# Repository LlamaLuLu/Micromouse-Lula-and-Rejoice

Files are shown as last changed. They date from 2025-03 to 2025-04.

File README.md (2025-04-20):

# 🐭 Micromouse Power Subsystem – EEE3088F 2025

> A modular and cost-efficient power subsystem designed for the Micromouse platform, focusing on power delivery, battery management, voltage regulation, and motor control.  
> 🔧 Built to integrate with a shared motherboard using a 2×16 pin header.

---

## 📐 Design Requirements

- Must interface with **shared motherboard via 2×16 pin header**
- All subsystems must **interoperate safely and reliably**
- Total cost must not exceed **$28.25 per student**
- Designed with **PCB production in mind** (JLCPCB compatible)

---

## ⚡ Subsystems Overview

### 1. USB-C Power Input
- **Objective**: Extract and regulate power from USB-C
- **Default Output**: 5V  
- **Target Output**: 9V
- **Approaches**:
  - Step-up converter (boost from 5V)
  - Request 9V from port using USB PD (Power Delivery) negotiation

### 2. Battery Management
- **Battery**: 3.7V 800mAh LiPo (used in micro robotics)
- **Charging Input**: 9V (from USB-C)
- **Charging Modes**:
  - Low current: **200mA**
  - High current: **(600 ± 100)mA**
- **Key Considerations**:
  - LiPo is **sensitive to overcharging**
- **Design Strategies**:
  - Use a **battery management IC**
  - Dual-mode charging circuit (selectable)
    - Separate high- and low-current paths
  - OR: Current regulation on USB-C input side that supports both modes

### 3. Power Switching & Regulation

#### 🔌 Power Switch
- Enables/disables battery output to downstream circuits

#### 🔋 Voltage Regulation
- Battery output can supply up to **400mA**
- **Approach**: Efficient voltage regulation using buck converters
- **Protection**: Optional current amplification for regulated rails

#### 🔀 External Load Switching
- Must control **2 external loads**, each up to **1A**
- **Solution**: High-current **MOSFET switching circuits**
- Current path design considers **external load values**

### 4. Components & Motor Drivers

#### 🔍 Current Sensor
- **INA219** or similar  
- Connects via **I²C**  
- Placed on high-side battery line for real-time monitoring

#### 🚗 Motor Control
- **Primary Motors**: 2 × 200mA  
- **Auxiliary Motors**: 2 × 500mA  
- Control via **dual H-bridge** motor driver (e.g., DRV8833)
- Motors driven bidirectionally using **PWM from MCU**

---

## 🧰 Production & Submission Instructions (EEE3088F)

The final PCB submission is in a zipped folder:
[Final PCB Files](./EEE3088F_PCB_Project/jlcpcb/production_files/EEE3088F_2025_Project_PCB_Files_Group_66_LNGLUL002_MTMREJ003.zip)

_ZIP File Includes:_
1. Zipped **Gerber** files (with silkscreen including group & student numbers)
2. **BOM `.csv`** file  
3. **POS/CPL `.csv`** file  
4. Screenshot of **JLCPCB BOM upload** page  
5. Screenshot of **JLCPCB Add to Cart** confirmation page  

📷 PCB Design:
- Schematic
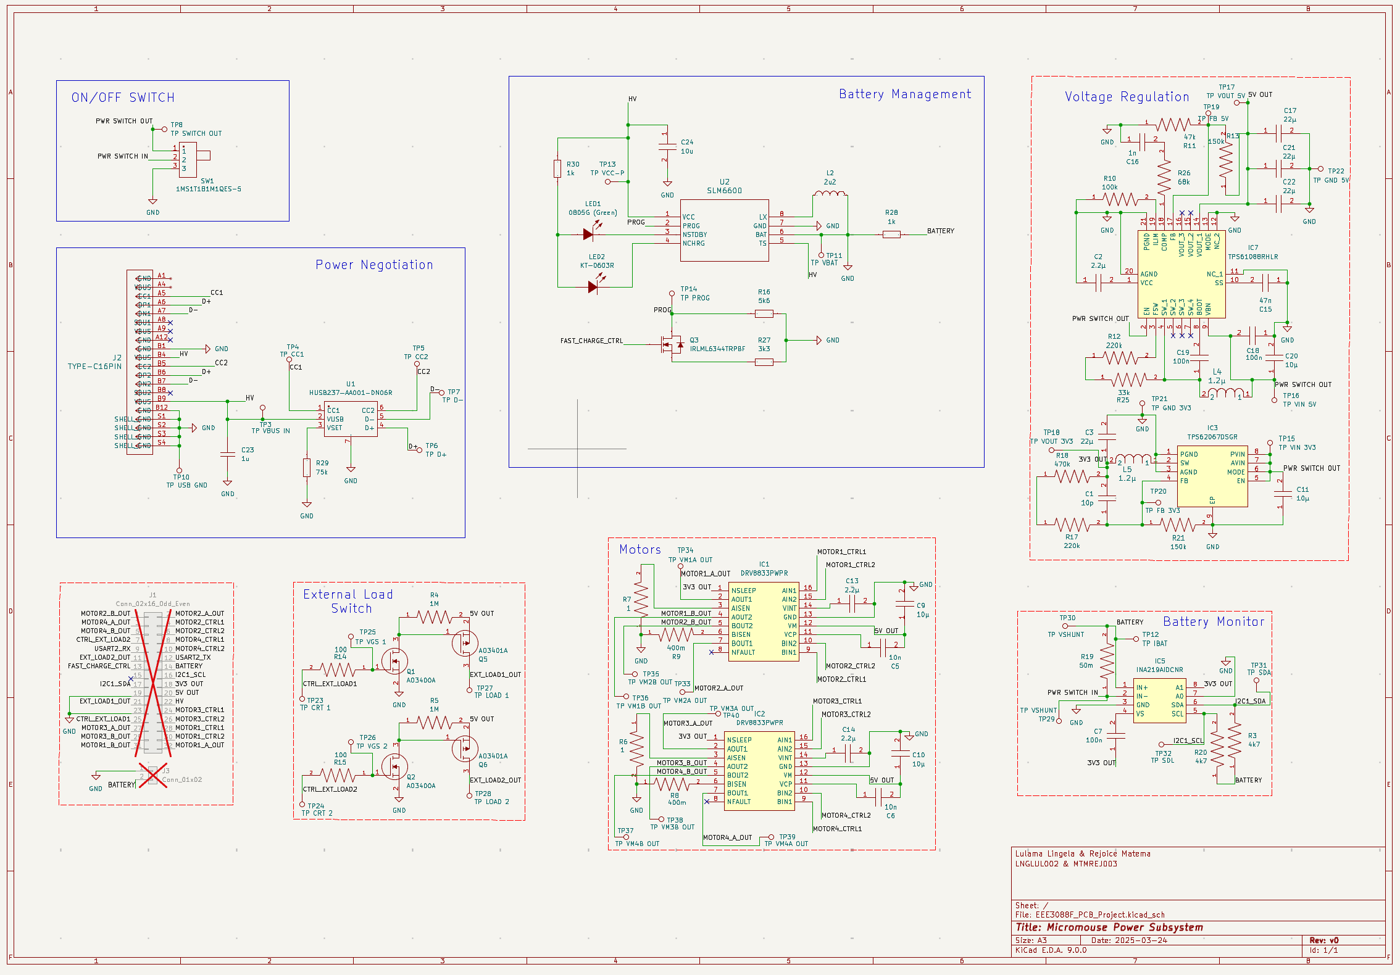
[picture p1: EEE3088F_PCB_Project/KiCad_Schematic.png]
KiCad Schematic

- PCB Wiring
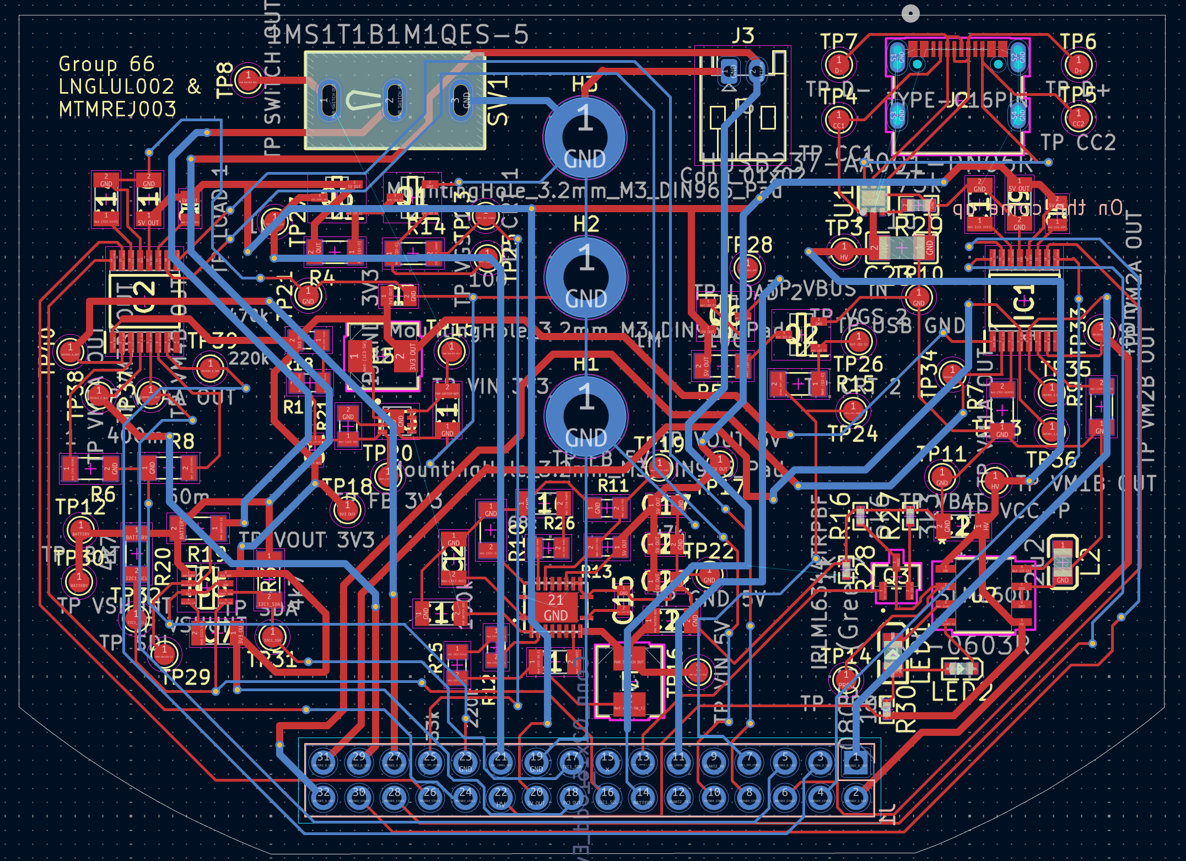
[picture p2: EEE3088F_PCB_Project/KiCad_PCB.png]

- JLCPCB Design (Front)
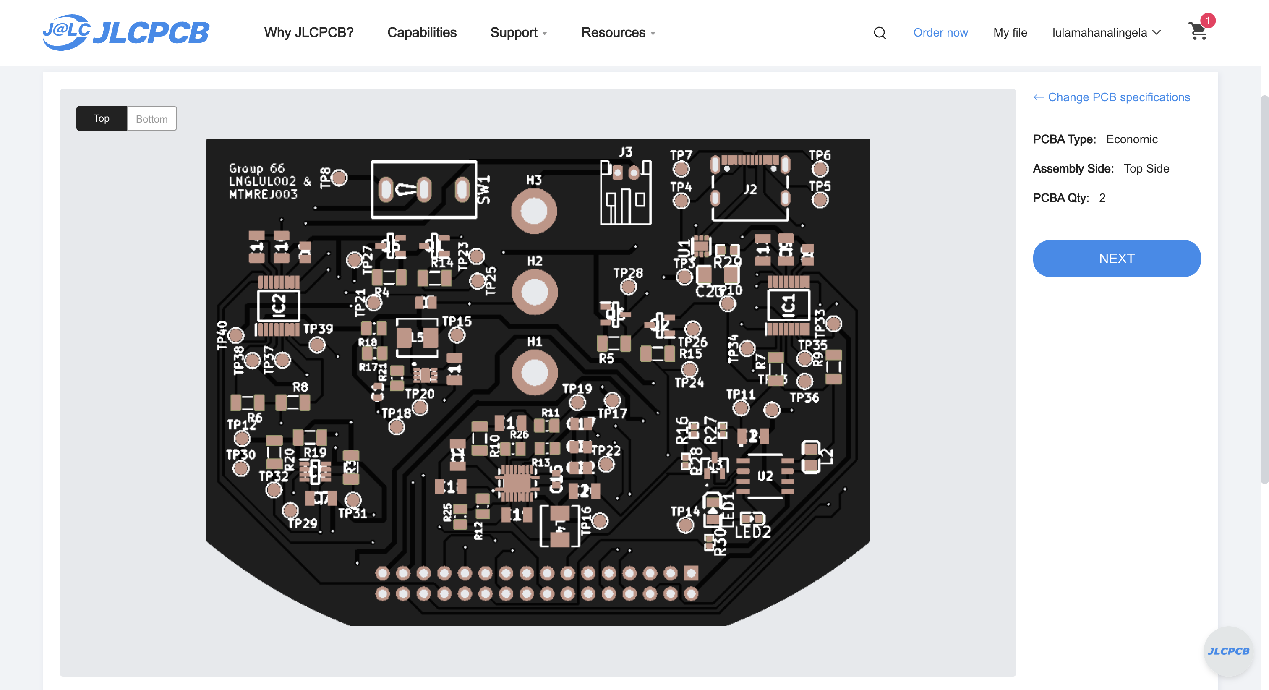
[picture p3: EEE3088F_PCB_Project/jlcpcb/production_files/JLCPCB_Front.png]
JLCPCB Acceptance Screenshot

- JLCPCB Design (Back)
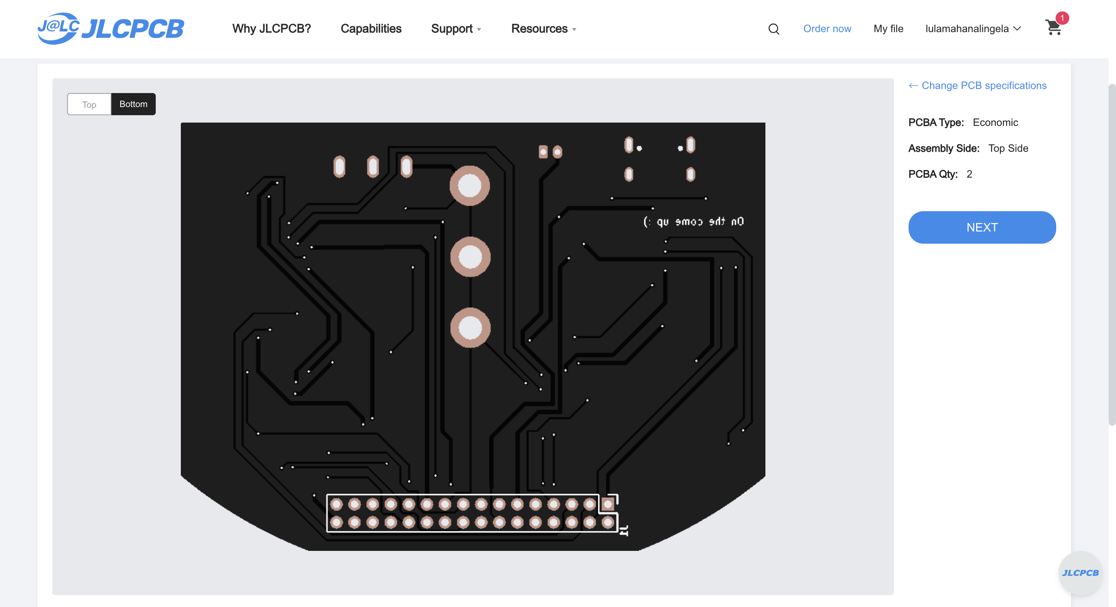
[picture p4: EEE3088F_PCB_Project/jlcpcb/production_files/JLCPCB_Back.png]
JLCPCB Acceptance Screenshot


---

## 👨‍💻 Authors: Group 66

- **Lulama Lingela** (LNGLUL002)
- **Rejoice Matema** (MTMREJ003)

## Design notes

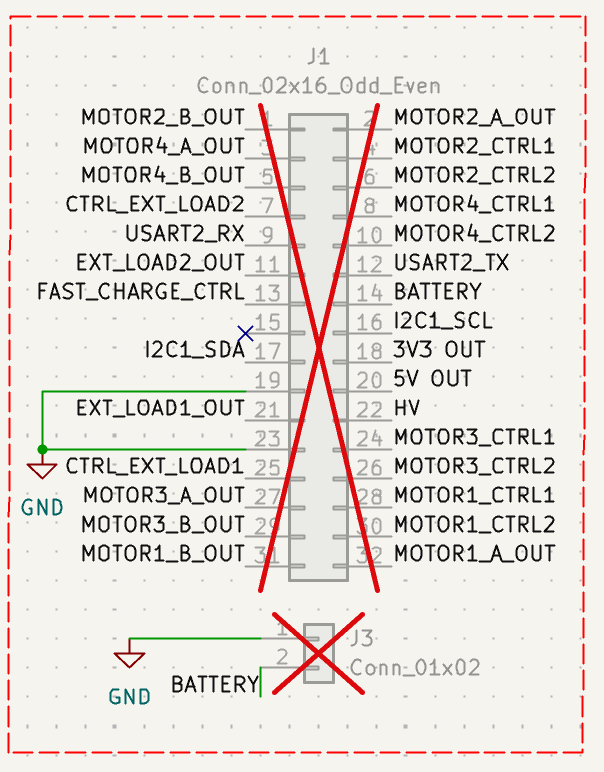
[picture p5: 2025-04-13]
EEE3088F_PCB_Project/schematics v1/Screenshot 2025-03-28 at 20.44.02.png

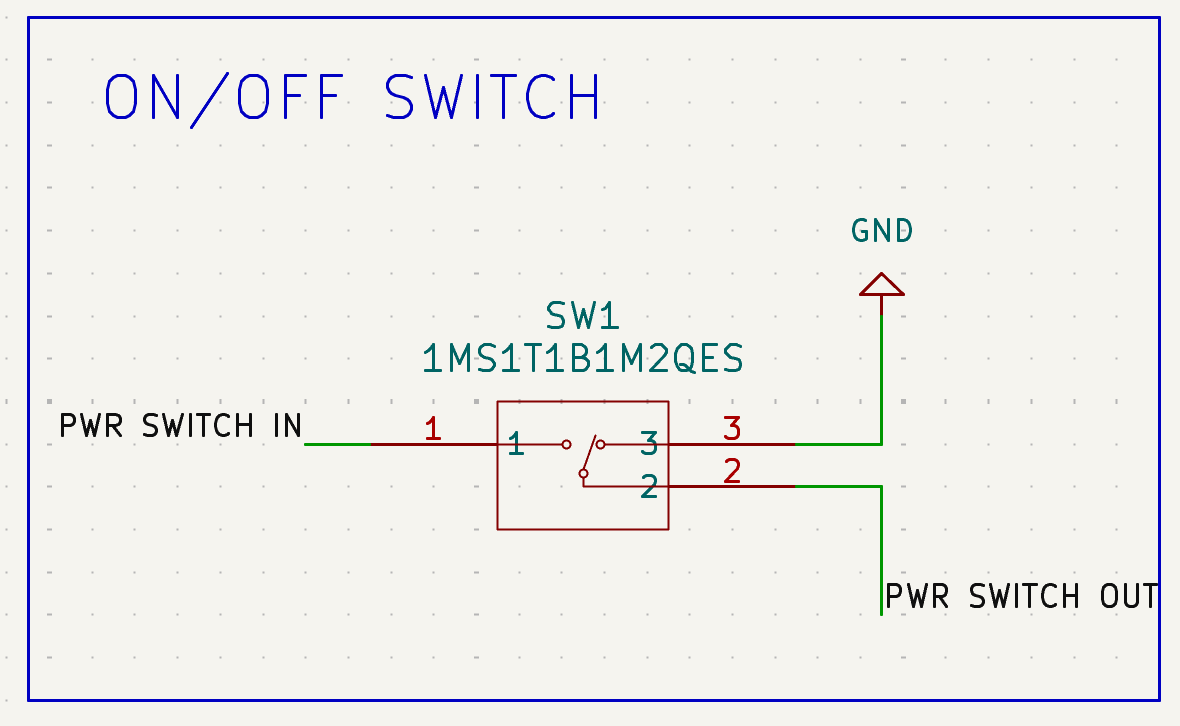
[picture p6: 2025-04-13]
EEE3088F_PCB_Project/schematics v1/Screenshot 2025-03-28 at 20.43.12.png

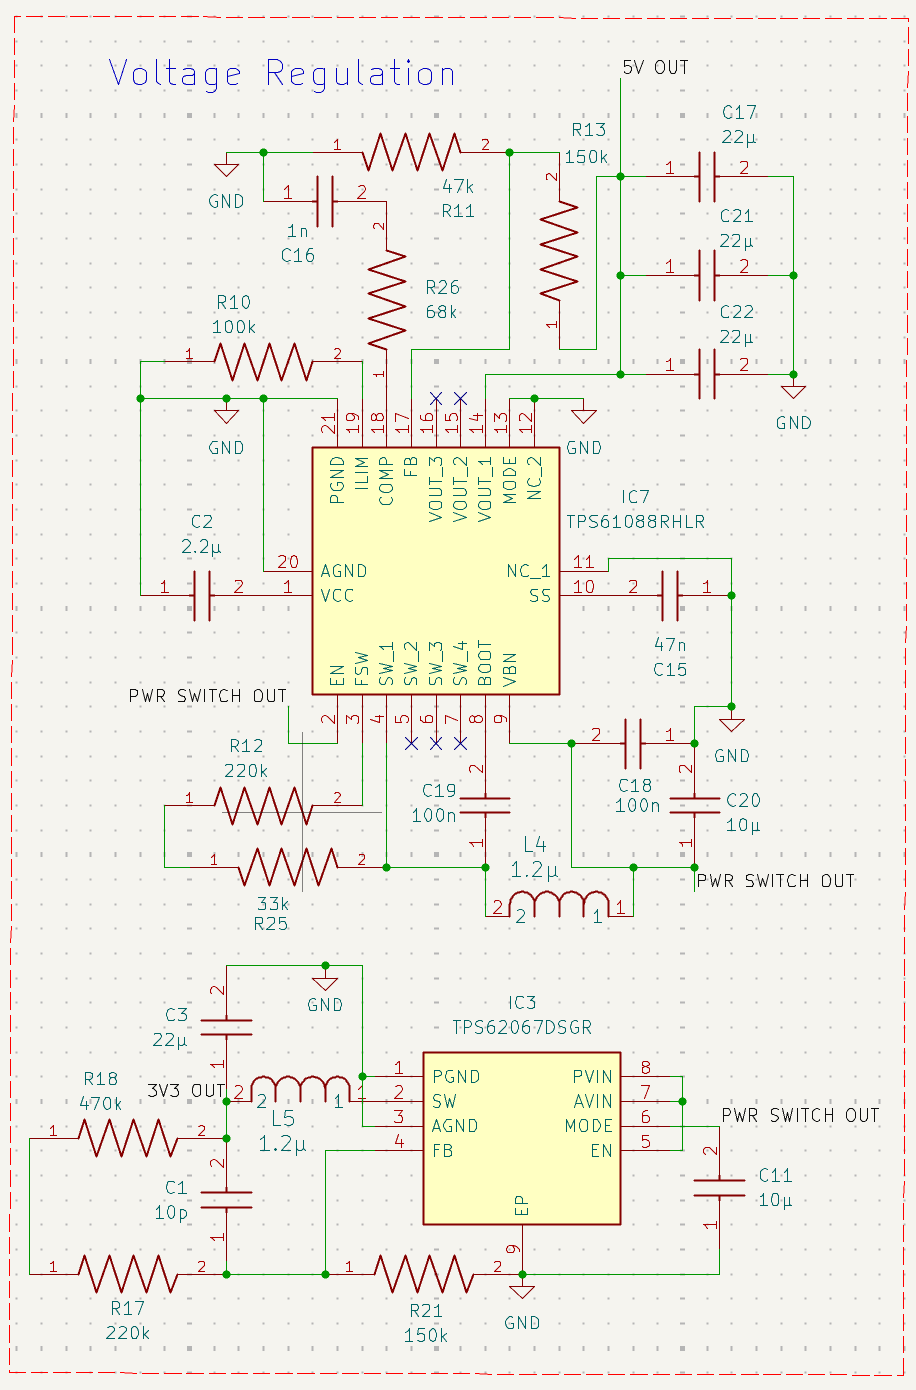
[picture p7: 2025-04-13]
EEE3088F_PCB_Project/schematics v1/Screenshot 2025-03-28 at 20.43.32.png

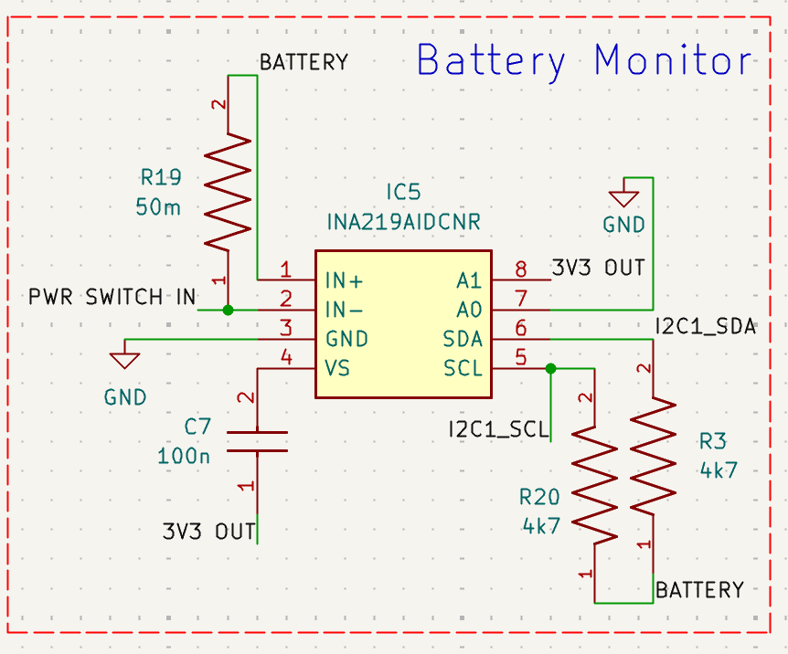
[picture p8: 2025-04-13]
EEE3088F_PCB_Project/schematics v1/Screenshot 2025-03-28 at 20.43.53.png

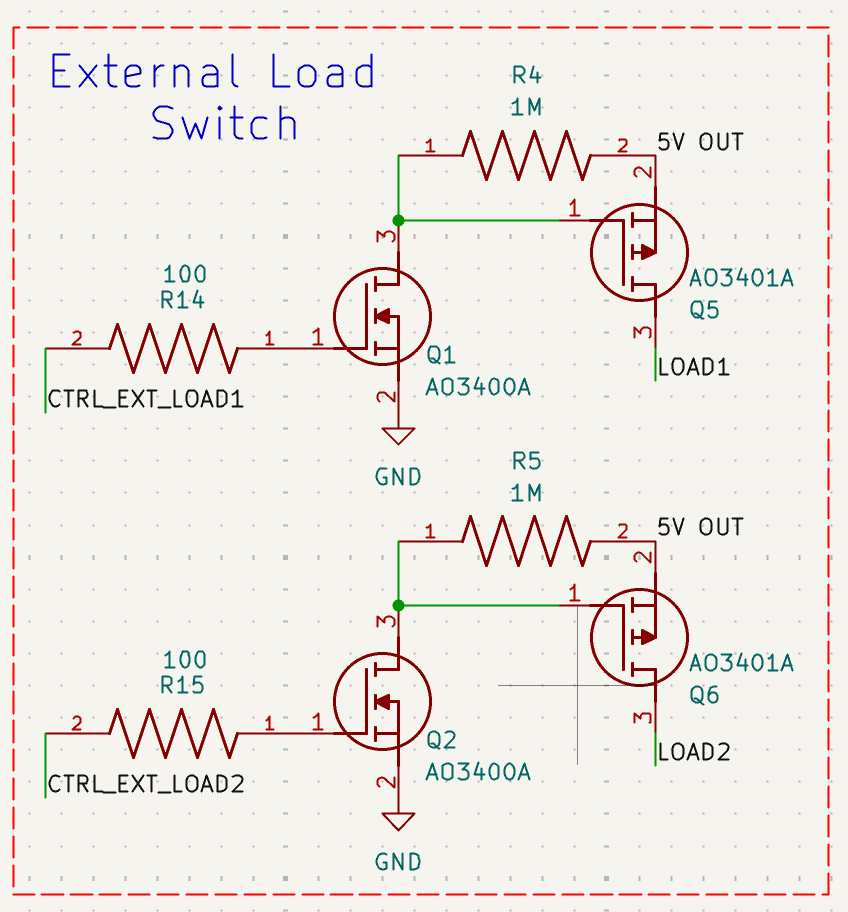
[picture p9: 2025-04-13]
EEE3088F_PCB_Project/schematics v1/Screenshot 2025-03-28 at 20.43.48.png

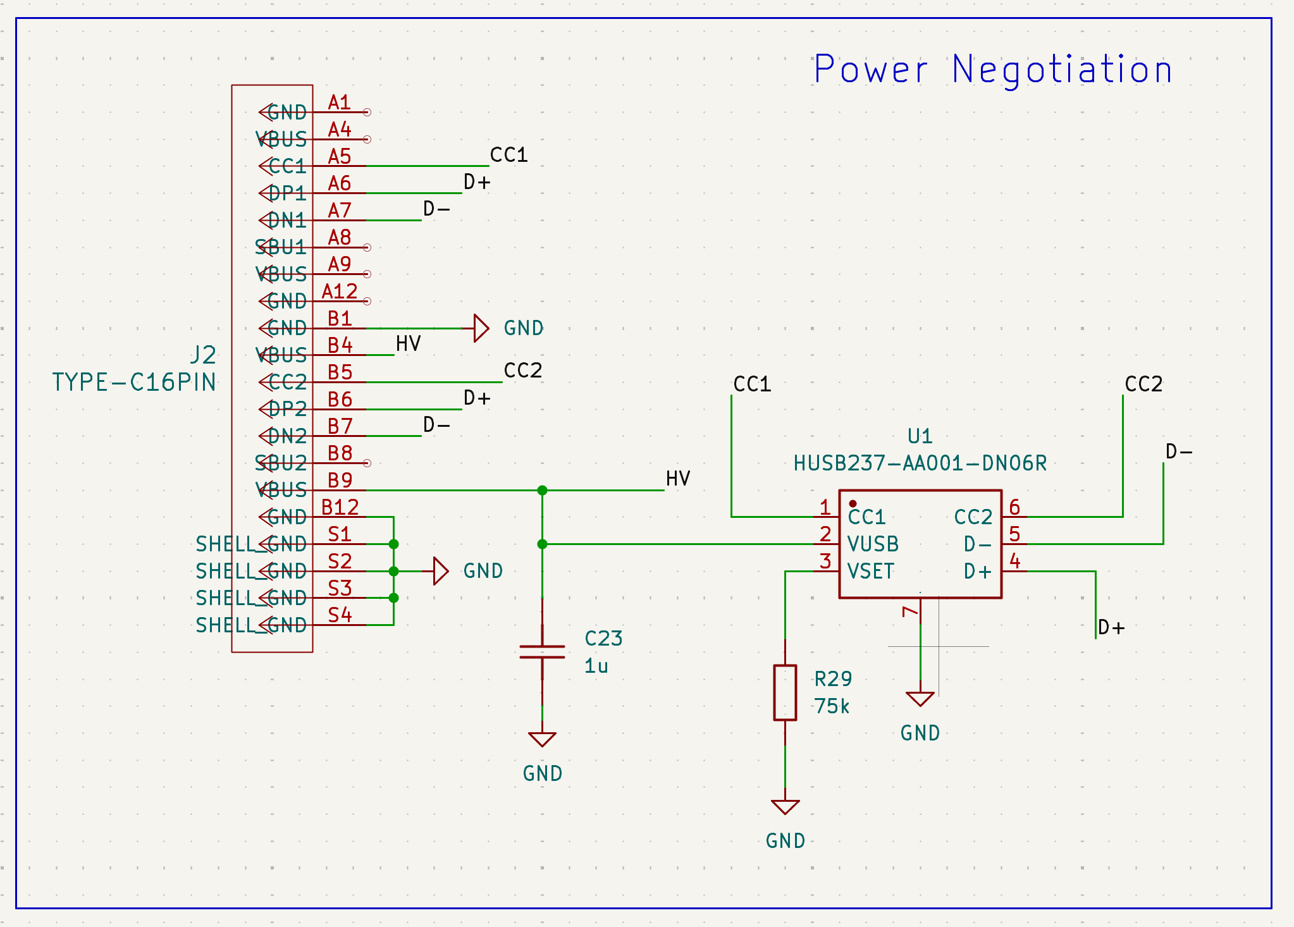
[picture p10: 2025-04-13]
EEE3088F_PCB_Project/schematics v1/Screenshot 2025-03-28 at 20.43.07.png

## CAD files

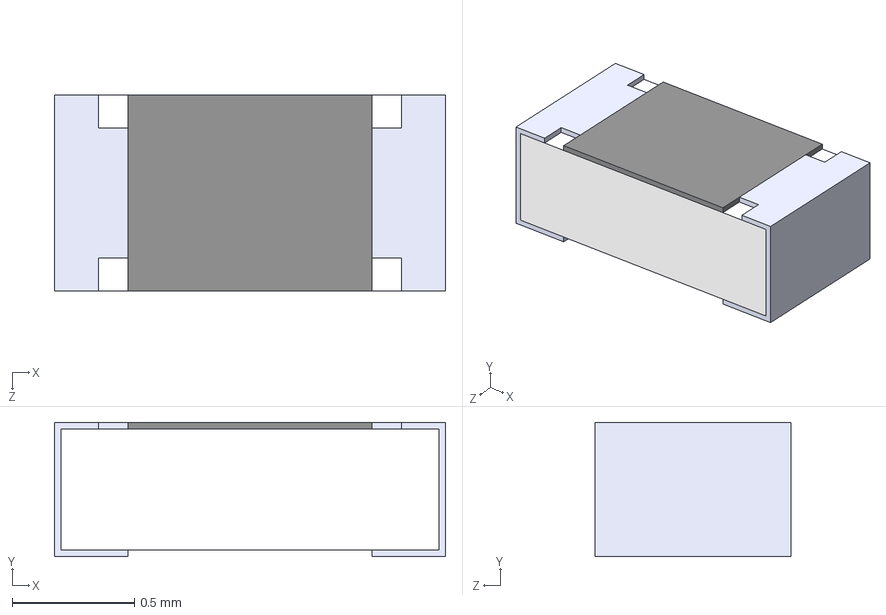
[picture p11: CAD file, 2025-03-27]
EEE3088F_PCB_Project/Imported components/0603WAF1203T5E/0603WAF1203T5E.step
1.60 x 0.55 x 0.8 mm

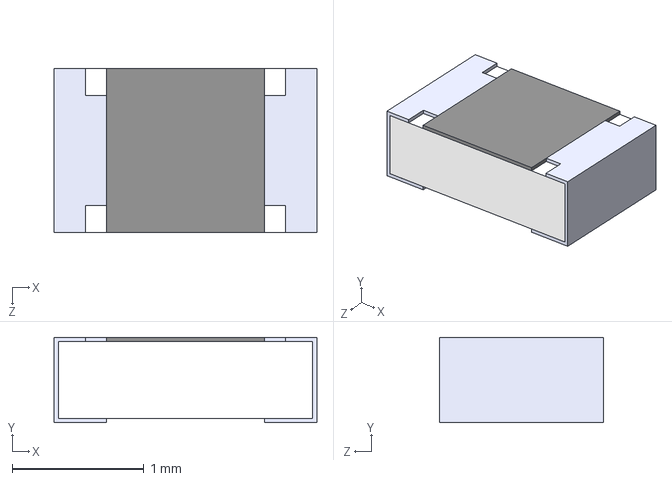
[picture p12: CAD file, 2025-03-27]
EEE3088F_PCB_Project/Imported components/0805W8F4702T5E/0805W8F4702T5E.step
2.00 x 0.65 x 1.25 mm

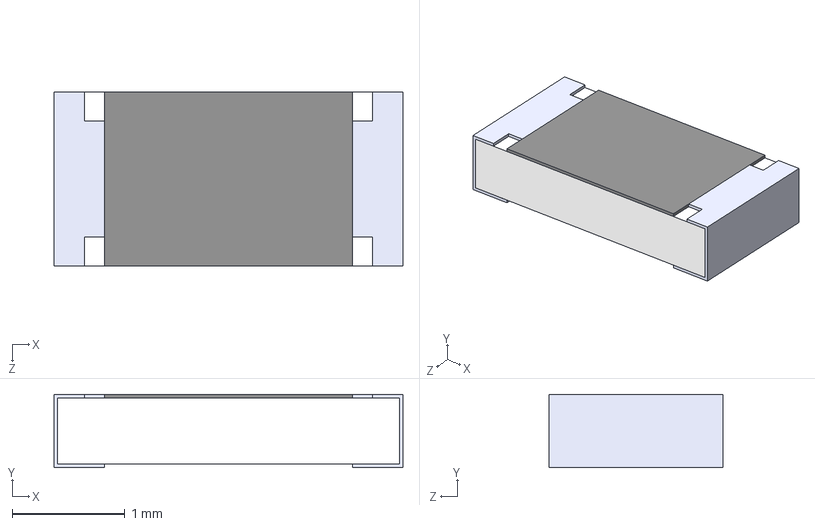
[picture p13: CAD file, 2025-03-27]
EEE3088F_PCB_Project/Imported components/1206W3F500MT5E/1206W3F500MT5E.step
3.10 x 0.65 x 1.55 mm

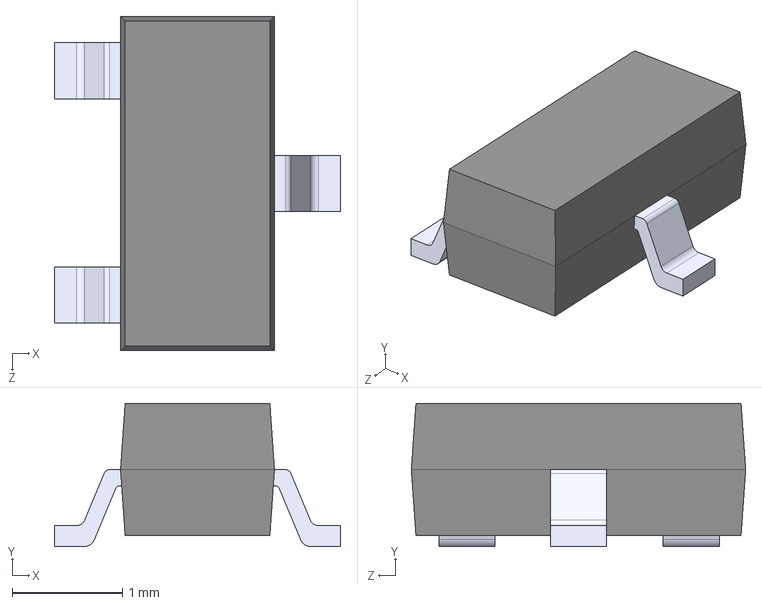
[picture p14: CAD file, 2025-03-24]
EEE3088F_PCB_Project/Imported components/MMBT2222A/MMBT2222A.step
2.60 x 1.30 x 3.04 mm

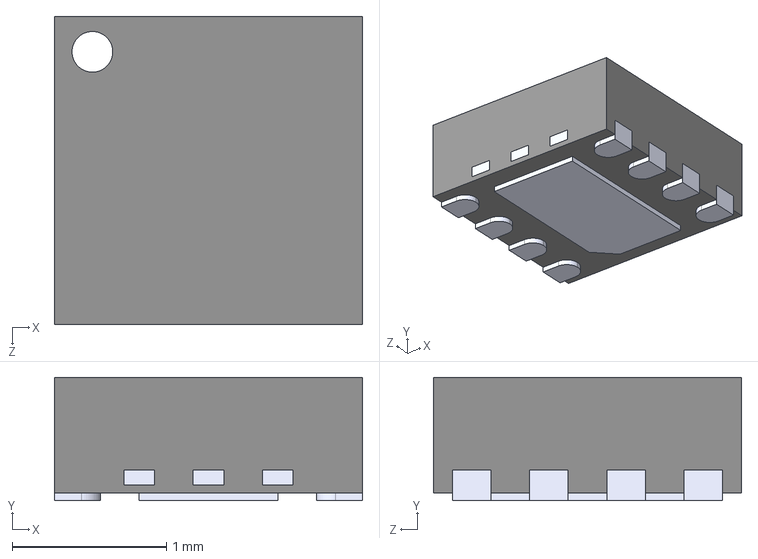
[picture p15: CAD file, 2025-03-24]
EEE3088F_PCB_Project/Imported components/TPS62067DSGR/TPS62067DSGR.step
2.00 x 0.8 x 2.00 mm

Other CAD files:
EEE3088F_PCB_Project/Imported components/1206W4F1004T5E/1206W4F1004T5E.step

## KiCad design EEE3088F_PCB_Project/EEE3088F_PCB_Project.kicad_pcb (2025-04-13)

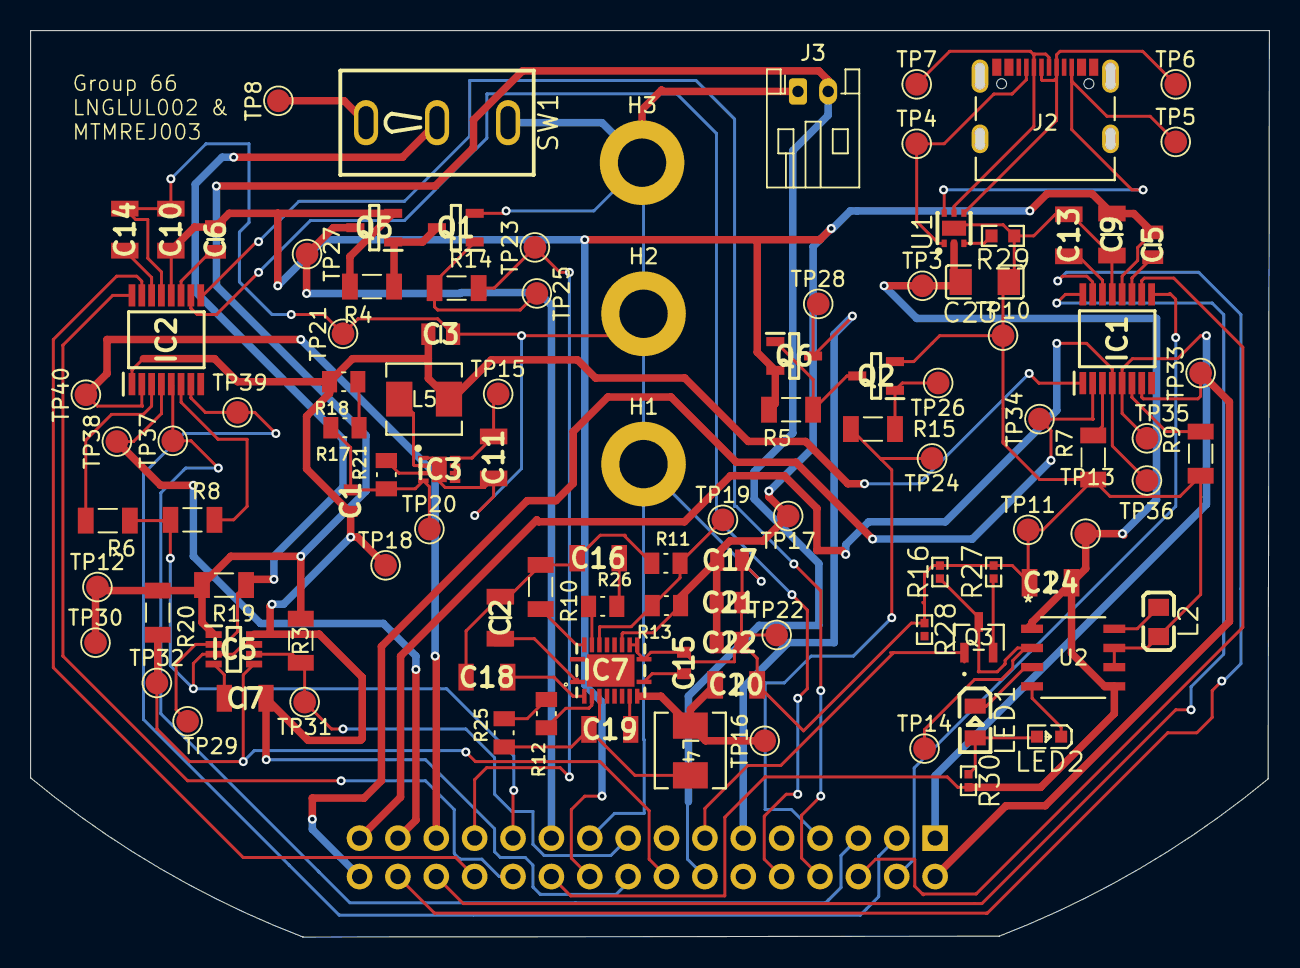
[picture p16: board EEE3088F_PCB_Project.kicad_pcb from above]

Board: 2 copper layers, 82.0 x 60.0 mm, 107 parts (1 on the bottom side), 67 nets.

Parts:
C1: 10p; CAPC1608X90N
C2, C13, C14: 2.2µ; CAPC3216X180N
C3, C17, C21, C22: 22µ; CAPC2012X140N
C5, C6: 10n; CAPC2012X75N
C7, C18, C19: 100n; CAPC3216X100N
C9, C10, C11, C20: 10µ; CAPC3216X180N
C15: 47n; CAPC1608X90N
C16: 1n; CAPC3215X163N
C23: 1u; C1206
C24: 10u; CAPC3216X180N
H1, H2, H3: MountingHole_3.2mm_M3_DIN965_Pad
IC1, IC2: DRV8833PWPR; SOP65P640X120-16N
IC3: TPS62067DSGR; SON50P200X200X80-9N
IC5: INA219AIDCNR; SOP65P280X145-8N
IC7: TPS61088RHLR; RHL_R-PVQFN-N20__1
J1: Conn_02x16_Odd_Even; PinSocket_2x16_P2.54mm_Vertical
J2: TYPE-C16PIN; CONN16_C16PIN_SHN
J3: Conn_01x02; JST_PH_S2B-PH-K_1x02_P2.00mm_Horizontal
L2: 2u2; L0805
L4, L5: 1.2µ; IND_FXL0420_CMT
LED1: 0805G (Green); LED0805-R-RD
LED2: KT-0603R; LED0603-RD
Q1, Q2: AO3400A; SOT95P280X125-3N
Q3: IRLML6344TRPBF; IRLML6344TRPBF_INF
Q5, Q6: AO3401A; SOT95P280X125-3N
R3, R20: 4k7; RESC3115X65N
R4, R5: 1M; RESC3115X65N
R6, R7: 1; RESC3115X65N
R8, R9: 400m; RESC3115X65N
R10: 100k; RESC3115X65N
R11: 47k; RESC2012X65N
R12, R17: 220k; RESC2012X65N
R13, R21: 150k; RESC2012X65N
R14, R15: 100; RESC3115X65N
R16: 5k6; R0402
R18: 470k; RESC2012X65N
R19: 50m; RESC3115X65N
R25: 33k; RESC2012X65N
R26: 68k; RESC2012X65N
R27: 3k3; R0402
R28, R30: 1k; R0402
R29: 75k; R0603
SW1: 1MS1T1B1M1QES-5; SW-TH_1MS1T1B1M1QES-5
TP3: TP VBUS IN; TestPoint_Pad_D1.5mm
TP4: TP CC1; TestPoint_Pad_D1.5mm
TP5: TP CC2; TestPoint_Pad_D1.5mm
TP6: TP D+; TestPoint_Pad_D1.5mm
TP7: TP D-; TestPoint_Pad_D1.5mm
TP8: TP SWITCH OUT; TestPoint_Pad_D1.5mm
TP10: TP USB GND; TestPoint_Pad_D1.5mm
TP11: TP VBAT; TestPoint_Pad_D1.5mm
TP12: TP IBAT; TestPoint_Pad_D1.5mm
TP13: TP VCC-P; TestPoint_Pad_D1.5mm
TP14: TP PROG; TestPoint_Pad_D1.5mm
TP15: TP VIN 3V3; TestPoint_Pad_D1.5mm
TP16: TP VIN 5V; TestPoint_Pad_D1.5mm
TP17: TP VOUT 5V; TestPoint_Pad_D1.5mm
TP18: TP VOUT 3V3; TestPoint_Pad_D1.5mm
TP19: TP FB 5V; TestPoint_Pad_D1.5mm
TP20: TP FB 3V3; TestPoint_Pad_D1.5mm
TP21: TP GND 3V3; TestPoint_Pad_D1.5mm
TP22: TP GND 5V; TestPoint_Pad_D1.5mm
TP23: TP CRT 1; TestPoint_Pad_D1.5mm
TP24: TP CRT 2; TestPoint_Pad_D1.5mm
TP25: TP VGS 1; TestPoint_Pad_D1.5mm
TP26: TP VGS 2; TestPoint_Pad_D1.5mm
TP27: TP LOAD 1; TestPoint_Pad_D1.5mm
TP28: TP LOAD 2; TestPoint_Pad_D1.5mm
TP29, TP30: TP VSHUNT; TestPoint_Pad_D1.5mm
TP31: TP SDA; TestPoint_Pad_D1.5mm
TP32: TP SDL; TestPoint_Pad_D1.5mm
TP33: TP VM2A OUT; TestPoint_Pad_D1.5mm
TP34: TP VM1A OUT; TestPoint_Pad_D1.5mm
TP35: TP VM2B OUT; TestPoint_Pad_D1.5mm
TP36: TP VM1B OUT; TestPoint_Pad_D1.5mm
TP37: TP VM4B OUT; TestPoint_Pad_D1.5mm
TP38: TP VM3B OUT; TestPoint_Pad_D1.5mm
TP39: TP VM4A OUT; TestPoint_Pad_D1.5mm
TP40: TP VM3A OUT; TestPoint_Pad_D1.5mm
U1: HUSB237-AA001-DN06R; TDFN-6_L2.0-W2.0-P0.65-TL-EP
U2: SLM6600; SOP8_4X5P1-1P27_SOI

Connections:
/3V3 OUT: C1.2, C3.1, C7.1, IC1.1 (NSLEEP), IC2.1 (NSLEEP), IC5.8 (A1), J1.18, L5.2, R18.2, TP18.1
/5V OUT: C5.2, C6.2, C9.1, C10.1, C17.1, C21.1, C22.1, IC1.12 (VM), IC2.12 (VM), IC7.14 (VOUT_1), J1.20, Q5.2 (S), Q6.2 (S), R4.2, R5.2, R13.1, TP17.1
/BATTERY: IC5.1 (IN+), J1.14, J3.2, R3.1, R19.2, R20.1, R28.2, TP12.1, TP30.1
/CC1: J2.A5 (CC1), TP4.1, U1.1 (CC1)
/CC2: J2.B5 (CC2), TP5.1, U1.6 (CC2)
/CTRL_EXT_LOAD1: J1.25, R14.2, TP23.1
/CTRL_EXT_LOAD2: J1.7, R15.2, TP24.1
/D+: J2.A6 (DP1), J2.B6 (DP2), TP6.1, U1.4 (D+)
/D-: J2.A7 (DN1), J2.B7 (DN2), TP7.1, U1.5 (D-)
/EXT_LOAD1_OUT: J1.21, Q5.3 (D), TP27.1
/EXT_LOAD2_OUT: J1.11, Q6.3 (D), TP28.1
/FAST_CHARGE_CTRL: J1.13, Q3.1 (G)
/HV: C23.2, C24.1, J1.22, J2.B4 (VBUS), J2.B9 (VBUS), R30.2, TP3.1, TP13.1, U1.2 (VUSB), U2.1 (VCC), U2.5 (TS)
/I2C1_SCL: IC5.5 (SCL), J1.16, R20.2, TP32.1
/I2C1_SDA: IC5.6 (SDA), J1.17, R3.2, TP31.1
/MOTOR1_A_OUT: IC1.2 (AOUT1), J1.32, TP34.1
/MOTOR1_B_OUT: IC1.4 (AOUT2), J1.31, TP36.1
/MOTOR1_CTRL1: IC1.16 (AIN1), J1.28
/MOTOR1_CTRL2: IC1.15 (AIN2), J1.30
/MOTOR2_A_OUT: IC1.7 (BOUT1), J1.2, TP33.1
/MOTOR2_B_OUT: IC1.5 (BOUT2), J1.1, TP35.1
/MOTOR2_CTRL1: IC1.9 (BIN1), J1.4
/MOTOR2_CTRL2: IC1.10 (BIN2), J1.6
/MOTOR3_A_OUT: IC2.2 (AOUT1), J1.27, TP40.1
/MOTOR3_B_OUT: IC2.4 (AOUT2), J1.29, TP38.1
/MOTOR3_CTRL1: IC2.16 (AIN1), J1.24
/MOTOR3_CTRL2: IC2.15 (AIN2), J1.26
/MOTOR4_A_OUT: IC2.7 (BOUT1), J1.3, TP39.1
/MOTOR4_B_OUT: IC2.5 (BOUT2), J1.5, TP37.1
/MOTOR4_CTRL1: IC2.9 (BIN1), J1.8
/MOTOR4_CTRL2: IC2.10 (BIN2), J1.10
/PROG: Q3.3 (D), R16.1, TP14.1, U2.2 (PROG)
/PWR SWITCH IN: IC5.2 (IN-), R19.1, SW1.2, TP29.1
/PWR SWITCH OUT: C11.2, C18.2, C20.1, IC3.5 (EN), IC3.6 (MODE), IC3.7 (AVIN), IC3.8 (PVIN), IC7.2 (EN), IC7.9 (VBN), L4.1, SW1.1, TP8.1, TP15.1, TP16.1
GND: C2.1, C3.2, C9.2, C10.2, C11.1, C13.2, C14.2, C15.1, C16.1, C17.2, C18.1, C20.2, C21.2, C22.2, C23.1, C24.2, H1.1, H2.1, H3.1, IC1.13 (GND), IC2.13 (GND), IC3.1 (PGND), IC3.3 (AGND), IC3.9 (EP), IC5.3 (GND), IC5.7 (A0), IC7.11 (NC_1), IC7.12 (NC_2), IC7.13 (MODE), IC7.20 (AGND), IC7.21 (PGND), J1.19, J1.23, J2.B1 (GND), J2.B12 (GND), J2.S1 (SHELL_GND), J2.S2 (SHELL_GND), J2.S3 (SHELL_GND), J2.S4 (SHELL_GND), J3.1, L2.2, Q1.2 (S), Q2.2 (S), R6.2, R7.1, R8.1, R9.1, R10.1, R11.1, R16.2, R21.2, R27.2, R28.1, R29.1, SW1.3, TP10.1, TP11.1, TP21.1, TP22.1, U1.7 (GND), U2.6 (BAT), U2.7 (GND)
unnamed: C16.2, R26.2
unnamed: IC1.3 (AISEN), R7.2
unnamed: IC1.6 (BISEN), R9.2
unnamed: C5.1, IC1.11 (VCP)
unnamed: C13.1, IC1.14 (VINT)
unnamed: IC2.3 (AISEN), R6.1
unnamed: IC2.6 (BISEN), R8.2
unnamed: C6.1, IC2.11 (VCP)
unnamed: C14.1, IC2.14 (VINT)
unnamed: C1.1, IC3.4 (FB), R17.2, R21.1, TP20.1
unnamed: IC3.2 (SW), L5.1
unnamed: C7.2, IC5.4 (VS)
unnamed: C19.2, IC7.8 (BOOT)
unnamed: IC7.18 (COMP), R26.1
unnamed: IC7.17 (FB), R11.2, R13.2, TP19.1
unnamed: IC7.3 (FSW), R12.2
unnamed: IC7.19 (ILIM), R10.2
unnamed: C15.2, IC7.10 (SS)
unnamed: C19.1, IC7.4 (SW_1), L4.2, R25.2
unnamed: C2.2, IC7.1 (VCC)
unnamed: LED1.1 (A), LED2.2 (A), R30.1
unnamed: LED1.2 (K), U2.3 (NSTDBY)
unnamed: LED2.1 (K), U2.4 (NCHRG)
unnamed: Q1.3 (D), Q5.1 (G), R4.1
unnamed: Q1.1 (G), R14.1, TP25.1
unnamed: Q2.3 (D), Q6.1 (G), R5.1
unnamed: Q2.1 (G), R15.1, TP26.1
unnamed: Q3.2 (S), R27.1
unnamed: R12.1, R25.1
unnamed: R17.1, R18.1
unnamed: R29.2, U1.3 (VSET)
unnamed: L2.1, U2.8 (LX)

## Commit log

2025-03-24 v0
    KiCad project set up
    [EEE3088F_PCB_Project.kicad_pcb, EEE3088F_PCB_Project.kicad_sch]
2025-03-24 v0.1
    Lula: Essential components for my requirements imported to KiCad
    [AO3401A.step, DRV8833PWPR.step, EEE3088F_PCB_Project.kicad_sch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]
2025-03-24 v0.1.1
    Lula: Rearranged position of components to make space for others
    [EEE3088F_PCB_Project.kicad_sch]
2025-03-24 v0.1.2
    Lula: Updated ICs with more compact symbols from Component Search Engine
    [DRV8833PWPR.step, EEE3088F_PCB_Project.kicad_sch, INA219AIDCNR.step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]
2025-03-24 v0.1.3
    Lula: Deleted old IC file
    [AO3401A.step]
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2025-03-25 v0.2
    Lula: rough battery monitor circuit done
    [EEE3088F_PCB_Project.kicad_sch]
2025-03-25 v0.2.1
    Lula: Making progress with Motor cct
    [EEE3088F_PCB_Project.kicad_sch]
2025-03-25 v0.3
    Lula: rough schematic for motors done
    [EEE3088F_PCB_Project.kicad_sch]
2025-03-25 v0.4
    Lula: rough voltage regulator circuits done but bias resistor values not calculated
    [EEE3088F_PCB_Project.kicad_sch, TPS62067DSGR.step]
2025-03-26 v0.5
    Lula: all my rough circuits done
    [EEE3088F_PCB_Project.kicad_sch]
2025-03-26 v0.6
    Lula:
    - motors done
    - some pcb footprints added
    - imports updated
    [1206W4F400LT5E.step, EEE3088F_PCB_Project.kicad_pcb, EEE3088F_PCB_Project.kicad_sch]
2025-03-26 v0.6.1
    Lula: starting to update battery monitor circuit
    [EEE3088F_PCB_Project.kicad_sch]
2025-03-27 v0.6.2
    Lula: all battery monitor components imported
    [1206W3F500MT5E.step, 1206W4F4701T5E.step, EEE3088F_PCB_Project.kicad_sch]
2025-03-27 v0.6.3
    Lula: external load switch cct updated
    [0805W8F2702T5E.step, 1206W4F1002T5E.step, EEE3088F_PCB_Project.kicad_sch]
2025-03-27 v0.7
    - starting with new voltage regulation cct
    - all other components updated
    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
    [0603WAF1203T5E.step, 0603WAF3902T5E.step, 0805W8F1503T5E.step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]
2025-03-27 v0.7.2
    Lula: moved some circuits out of the way
    [EEE3088F_PCB_Project.kicad_sch]
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2025-03-28 v0.8
    - updated voltage regulation circuit (still adjusting component values)
    [EEE3088F_PCB_Project.kicad_sch]
2025-03-28 v0.8.1
    Voltage regulator components updated
    [0805W8F4702T5E.step, EEE3088F_PCB_Project.kicad_sch]
2025-03-28 v0.8.3
    A lot of stuff happened
    [EEE3088F_PCB_Project.kicad_sch]
2025-03-28 Revert "v0.8.3"
    This reverts commit e022e12157d8067f7fb354b48d193a9b7dd025b4.
    [EEE3088F_PCB_Project.kicad_sch]
2025-03-28 v0.9
    Created my circuits in KiCad
    [EEE3088F_PCB_Project.kicad_sch]
2025-03-28 v1.0
    Changed V-REG to PWR SWITCH OUT
    [EEE3088F_PCB_Project.kicad_sch]
2025-03-28 v1.1
    All circuit schematics done
    [EEE3088F_PCB_Project.kicad_sch]
2025-03-28 v1.2
    Starting with PCB design
    [EEE3088F_PCB_Project.kicad_pcb, EEE3088F_PCB_Project.kicad_sch]
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2025-03-28 v1.3
    Lula: all my footprints imported and circuits grouped on PCB
    [EEE3088F_PCB_Project.kicad_pcb, EEE3088F_PCB_Project.kicad_sch]
2025-03-28 v1.3.1
    Most components placed on PCB
    [EEE3088F_PCB_Project.kicad_pcb, EEE3088F_PCB_Project.kicad_sch]
2025-03-28 v1.3.2
    Added test points to my parts of the circuit (and some)
    [EEE3088F_PCB_Project.kicad_sch]
2025-03-28 V1.3.3
    Added test points to my parts of the circuit
    [EEE3088F_PCB_Project.kicad_sch]
2025-03-28 v1.3.4
    test points added
    [EEE3088F_PCB_Project.kicad_pcb, EEE3088F_PCB_Project.kicad_sch]
2025-03-28 V1.4
    FAILED
    [EEE3088F_PCB_Project.kicad_pcb, EEE3088F_PCB_Project.kicad_sch]
2025-03-28 Revert "V1.4"
    This reverts commit e5222738783ebac659cce19e32834096aa7270f5.
    [EEE3088F_PCB_Project.kicad_pcb, EEE3088F_PCB_Project.kicad_sch]
2025-03-28 Revert "v1.3.4"
    This reverts commit 31f4348740902cc06db09578befa2d9091b6bdd9.
    [EEE3088F_PCB_Project.kicad_pcb, EEE3088F_PCB_Project.kicad_sch]
2025-03-28 Revert "V1.3.3"
    This reverts commit 82317ec0dd0d0933929f69b93ecb048d09c96738.
    [EEE3088F_PCB_Project.kicad_sch]
2025-03-28 V1.4.1
    last minute things
    [EEE3088F_PCB_Project.kicad_pcb]
2025-03-28 v1.4.2
    saving last minute changes
    [EEE3088F_PCB_Project.kicad_pcb, EEE3088F_PCB_Project.kicad_sch]
2025-03-28 v1.4
    new start - setup proper edge cuts
    [EEE3088F_PCB_Project.kicad_pcb]
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2025-03-28 v1.4.1
    - all footprints assigned
    - components neatly placed on PCB
    [EEE3088F_PCB_Project.kicad_pcb, EEE3088F_PCB_Project.kicad_sch]
2025-03-28 v1.4.2
    - inner shape removed from pcb
    [EEE3088F_PCB_Project.kicad_pcb]
2025-03-28 v1.5.1
    - tried adding wiring but hit edge
    [EEE3088F_PCB_Project.kicad_pcb]
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2025-03-28 Revert "v1.5.3"
    This reverts commit 1de1613c8c6e3748df64e612ca9ed2fbbcde8f2e.
    [EEE3088F_PCB_Project.kicad_pcb]
2025-03-28 Revert "v1.5.2"
    This reverts commit 51cb19e0555e6a1b099874e78e333fc85f141e8d.
    [EEE3088F_PCB_Project.kicad_pcb]
2025-03-28 Revert "v1.5.1"
    This reverts commit 95b0540061ed2b4f31283696902dc0dbdf64c944.
    [EEE3088F_PCB_Project.kicad_pcb]
2025-03-28 v1.4.3
    - added design rules & keep out area before wiring
    [EEE3088F_PCB_Project.kicad_pcb]
2025-03-29 v.1.4.4
    - updated PCB shape
    [EEE3088F_PCB_Project.kicad_pcb]
2025-03-29 v1.5
    - wiring done but at what cost
    [EEE3088F_PCB_Project.kicad_pcb]
2025-04-04 Revert "v1.5"
    This reverts commit 904848d5ff92434ff16791d24f5233f2f40037b0.
    [EEE3088F_PCB_Project.kicad_pcb]
2025-04-04 V1.4.5
    - assigned LCSC numbers to components
    [EEE3088F_PCB_Project.kicad_sch]
2025-04-04 v1.5
    - making progress with manual wiring
    [EEE3088F_PCB_Project.kicad_pcb, EEE3088F_PCB_Project.kicad_sch]
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2025-04-04 v1.5.2
    - resolved 'no connection' issue in battery management
    [EEE3088F_PCB_Project.kicad_pcb, EEE3088F_PCB_Project.kicad_sch]
2025-04-04 v1.5.3
    - started adding vias
    - making more progress with wiring
    [EEE3088F_PCB_Project.kicad_pcb, EEE3088F_PCB_Project.kicad_sch]
2025-04-05 v1.5.4
    - need to finish wiring to main connector
    [EEE3088F_PCB_Project.kicad_pcb, EEE3088F_PCB_Project.kicad_sch]
2025-04-05 v1.5.5
    - just need to connect motor pins
    [EEE3088F_PCB_Project.kicad_pcb, EEE3088F_PCB_Project.kicad_sch]
2025-04-05 v1.5.6
    - 4 more main connectors to go
    [EEE3088F_PCB_Project.kicad_pcb]
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
